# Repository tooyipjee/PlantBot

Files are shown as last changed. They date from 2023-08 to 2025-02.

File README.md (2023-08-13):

# Plant Bot: Automate Plant Care 🌱

<p align="center">
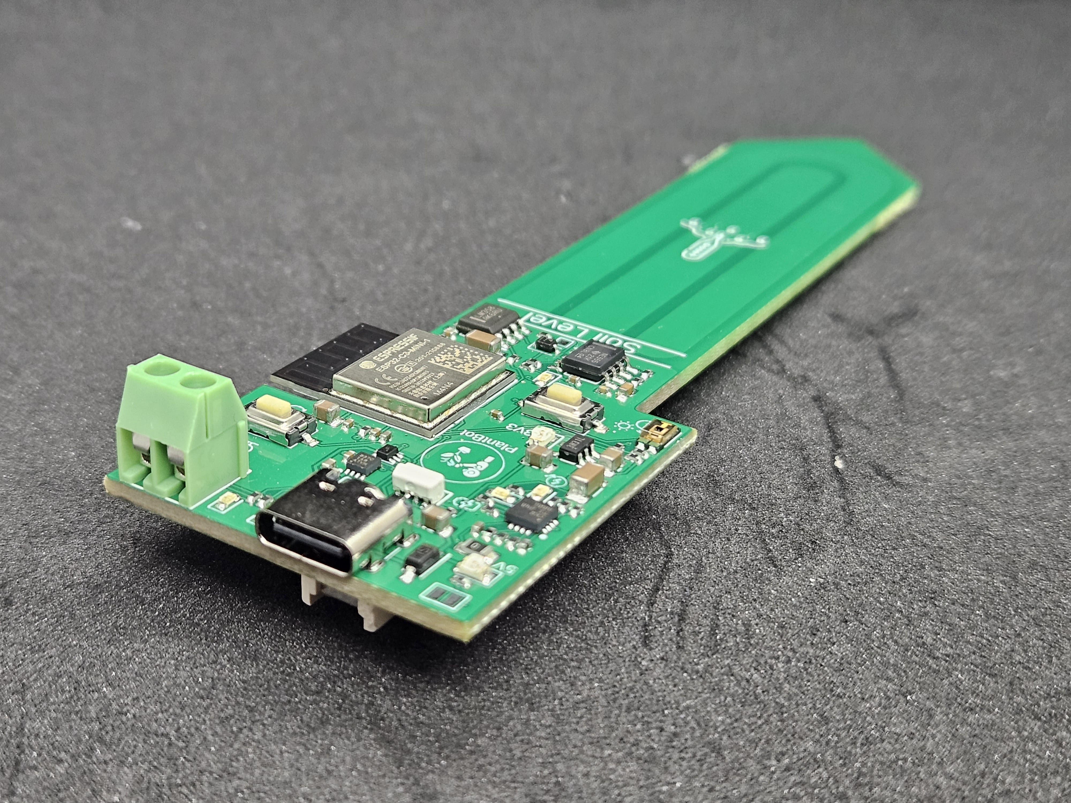
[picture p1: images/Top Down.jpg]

</p>

## High-Level Summary

Plant Bot is a cutting-edge device designed to revolutionize plant care. Powered by USB, it seamlessly integrates into your pot, transforming it into an active participant in plant care. With features like a moisture sensor, integrated pump driver, and multi-color LED control, it's the ultimate companion for every plant enthusiast.

Available on 

---

## Detailed Description

### What is it?

Plant Bot is not just a device; it's a solution to modern plant care challenges. Designed for both casual plant owners and enthusiasts, it offers:

- **Corrosion-Resistant Capacitive Moisture Sensor:** Say goodbye to guesswork. Know exactly when your plant needs water.
- **Integrated Pump Driver & LED Control:** Automated care with visual feedback. The LED's color spectrum ranges from red (indicating dry soil) to blue (indicating moist soil).
- **Connectivity:** With both WiFi and Bluetooth capabilities, stay connected with your plants from anywhere.
- **Battery-Powered Operation:** Designed as a low-power IoT device, ensuring longevity and reliability.

Leveraging open-source projects, Plant Bot supports programming via Micropython and Arduino. For advanced users, the ESP-IDF tool offers maximum customization.

---

## Use Cases

### Fully Automated Plant Care

The sample code provided showcases Plant Bot's capabilities in measuring soil moisture and light levels, taking actions based on the data. The intuitive LED color spectrum offers a visual representation of soil conditions, while an additional LED signals pump activation for hydration. Built on the ESP32 platform, it boasts comprehensive connectivity, transmitting data to platforms like Thingspeak.
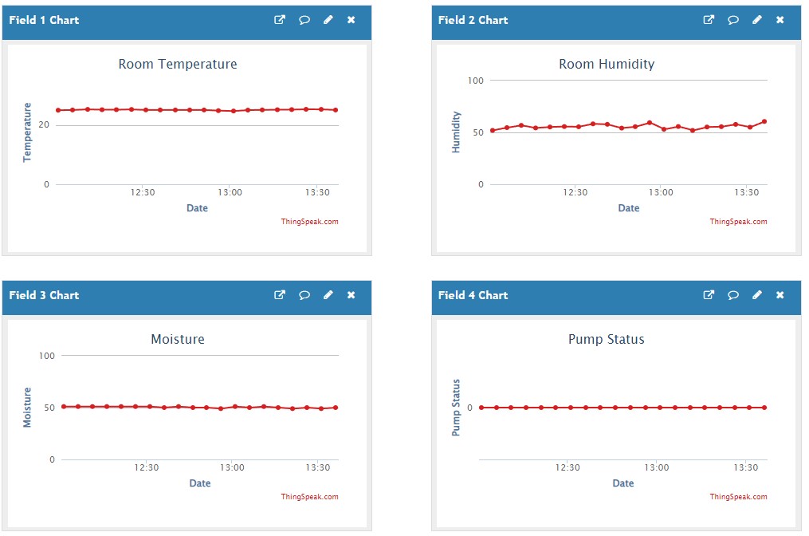
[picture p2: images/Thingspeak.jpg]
A snapshot of the data on Thingspeak showing moisture and light levels.


### Connected Plant Node

Harness the power of Plant Bot's low-power design to connect your plants to the internet wirelessly. Demos are available that allow Plant Bot to send Telegram notifications or relay measurements to IoT platforms. With efficient power consumption, a single coin cell battery can last up to a week with daily updates.

<p align="center">
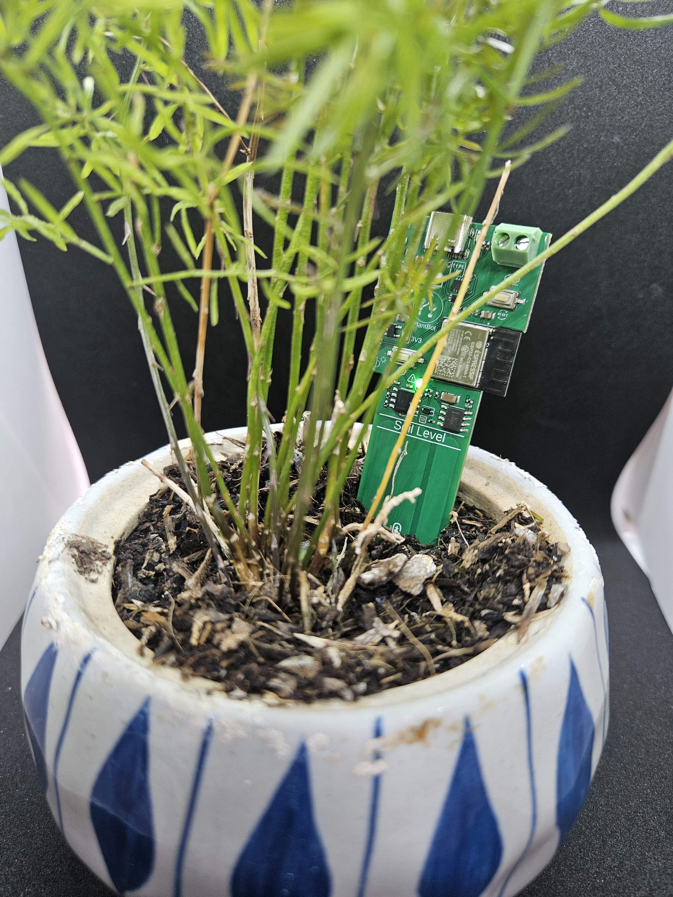
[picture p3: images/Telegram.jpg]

</p>

---

## How to Run the Demo Script

1. **Setup:** Ensure you have the Arduino IDE installed on your computer.
2. **Connect:** Plug in your ESP32-C3 device to your computer via USB.
3. **Integrated JTAG:** Ensure the JTAG is setup. In Tools, "USB CDC On Boot" is Enabled and JTAG Adapter is USB JTAG Adapter.
5. **Load Script:** Open one of the demo script provided in the Arduino IDE.
6. **Select Board:** From the 'Tools' menu, select 'Board' and choose 'ESP32-C3'.
7. **Select Port:** Select the port for the Plant-Bot device, if nothing pops up, unplug the device, hold the settings button and plug it back into the computer while still holding the button. It should appear now.
8. **Upload:** Click on the 'Upload' button to program the ESP32-C3.
9. **Monitor:** Open the Serial Monitor to view outputs and ensure the script runs successfully.

For any issues or further instructions, please refer to the documentation or raise an issue in the repo.

---

**Acknowledgments:** A special thank you to JLCPCB for their unwavering support throughout this project. Their expertise in rapid prototyping without compromising on quality has been invaluable.

## License

MIT License

Copyright (c) 2023 elektroThing

Permission is hereby granted, free of charge, to any person obtaining a copy
of this software and associated documentation files (the "Software"), to deal
in the Software without restriction, including without limitation the rights
to use, copy, modify, merge, publish, distribute, sublicense, and/or sell
copies of the Software, and to permit persons to whom the Software is
furnished to do so, subject to the following conditions:

The above copyright notice and this permission notice shall be included in all
copies or substantial portions of the Software.

THE SOFTWARE IS PROVIDED "AS IS", WITHOUT WARRANTY OF ANY KIND, EXPRESS OR
IMPLIED, INCLUDING BUT NOT LIMITED TO THE WARRANTIES OF MERCHANTABILITY,
FITNESS FOR A PARTICULAR PURPOSE AND NONINFRINGEMENT. IN NO EVENT SHALL THE
AUTHORS OR COPYRIGHT HOLDERS BE LIABLE FOR ANY CLAIM, DAMAGES OR OTHER
LIABILITY, WHETHER IN AN ACTION OF CONTRACT, TORT OR OTHERWISE, ARISING FROM,
OUT OF OR IN CONNECTION WITH THE SOFTWARE OR THE USE OR OTHER DEALINGS IN THE
SOFTWARE.

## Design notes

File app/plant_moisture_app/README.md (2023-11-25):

# plant_moisture_app

A new Flutter project.

## Getting Started

This project is a starting point for a Flutter application.

A few resources to get you started if this is your first Flutter project:

- [Lab: Write your first Flutter app](https://docs.flutter.dev/get-started/codelab)
- [Cookbook: Useful Flutter samples](https://docs.flutter.dev/cookbook)

For help getting started with Flutter development, view the
[online documentation](https://docs.flutter.dev/), which offers tutorials,
samples, guidance on mobile development, and a full API reference.

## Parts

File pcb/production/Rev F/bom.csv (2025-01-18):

Designator | Footprint | Quantity | Value | LCSC Part #
C10, C11, C12, C19, C3, C5, C8 | 0402 | 7 | 100n | C307331
C13, C15, C16, C7 | 0805 | 4 | 10u | C15850
C14 | 0402 | 1 | 1n | C1523
C17, C20, C9 | 0402 | 3 | 1u | C52923
C18, C6 | 1206 | 2 | 4.7u | C29823
C2 | 0603 | 1 | 470p | C1620
C4 | 0402 | 1 | 10n | C15195
D1 | D_SOD-323F | 1 | 1N4148WS | C2128
D10, D11, D2, D8 | 0603 | 4 | Green_0603 | C72043
D9 | B5819WSL | 1 | B5819W.SL | C8598
IC1 | SOIC127P600X175-8N | 1 | NE555DR | C7593
IC2 | SOIC127P600X175-8N | 1 | LM358DR2G | C7950
IC3 | ESP32C6MINI1N4 | 1 | ESP32-C6-MINI-1-N4 | C5736265
IC4 | AHT20 | 1 | AHT20 | C2757850
IC5 | QFN50P250X250X100-12N-D | 1 | TPS63051RMWR | C139412
IC6 | QFN50P300X300X100-17N-D | 1 | BQ24073RGTR | C15220
J1 | GT-USB-7010A | 1 | GT-USB-7010 | C963370
J2 | SM04BSRSSTBLFSN | 1 | SM04B-SRSS-TB__LF__SN_ | C160404
J3 | 2060452998404 | 1 | 2060-452_998-404 | C2765055
L1 | 0805 | 1 | 1.5uH | C2042639
Q1 | SOT95P237X125-3N | 1 | DTC143ECA-TP
Q2 | TEMT6000X01 | 1 | TEMT6000X01 | C94098
Q3 | DMP3007SFG7 | 1 | DMP3017SFG-7 | DMP3017SFG
R1, R2 | 0402 | 2 | 5.1k | C2906948
R10 | 0402 | 1 | 220 | C25091
R11, R14, R17, R18, R35, R5, R8 | 0402 | 7 | 10k | C25744
R12, R13 | 0402 | 2 | 1k | C11702
R16, R6 | 0402 | 2 | 1M | C26083
R22, R32, R33, R34, R36 | 0402 | 5 | 51k | C25794
R28, R29, R3 | 0402 | 3 | 1.5k | C25867
R30, R31, R7 | 0402 | 3 | 2.2k | C25879
R37 | 0603 | 1 | 560k | C23203
R38 | 0402 | 1 | 220k | C25767
R4 | 0402 | 1 | 2.4k | C25882
R9 | 0402 | 1 | 100 | C25076
S1, S2 | TS1101CW | 2 | TS-1101-C-W | C318938
TH2 | 0402 | 1 | 10k_NTC | C333993
TP1, TP2, TP3 | TestPoint_Pad_1.0x1.0mm | 3 | TestPoint_Alt
U2 | CR2032BS61 | 1 | CR2032-BS-6-1 | C70377

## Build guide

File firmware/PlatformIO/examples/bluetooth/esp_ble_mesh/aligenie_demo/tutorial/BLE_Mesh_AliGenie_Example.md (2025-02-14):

| Supported Targets | ESP32 |
| --- | ----- |

ESP BLE Mesh AliGenie Example
=============================

This demo shows how to use AliGenie to control the LED state. The basic procedures are as follows:

1. Go to the Ali IoT platform to apply for device triples.
2. Configure triples.
3. Download and run this demo.
4. Use AliGenie speakers or AliGenie app for BLE Mesh to provision.
5. After devices are provisioned, use voice interaction or app to control the LED state with AliGenie speakers.

# Basic Procedures

## 1. Apply Triples

## 1.1 Create Project

The first step in using the Ali IoT platform is to create a project. Data between projects is isolated from each other. Steps:

1. Log in to the console of the [Ali IoT platform](https://living.aliyun.com/?spm=a2c4g.11186623.2.13.4d219931TRSWJO).
2. Click Create Project.
3. Configure the project name.

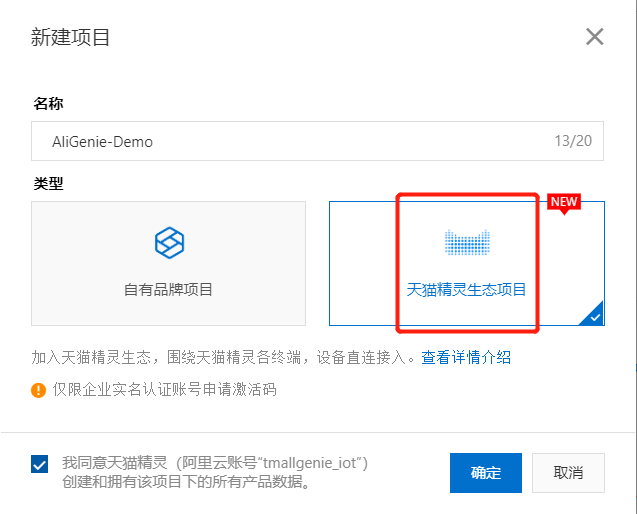
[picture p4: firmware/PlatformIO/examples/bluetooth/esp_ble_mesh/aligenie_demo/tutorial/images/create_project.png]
Create Project


## 1.2 Create Product

In each project, you can create multiple products. After the product is created, you can abstract the actual product into a data model composed of attributes, services, and events by defining product functions to facilitate cloud management and data interaction.

1. On the main project page, click Create New Product.
2. Configure product parameters
3. Click Finish. After the product is successfully created, it will automatically enter the product function definition page.

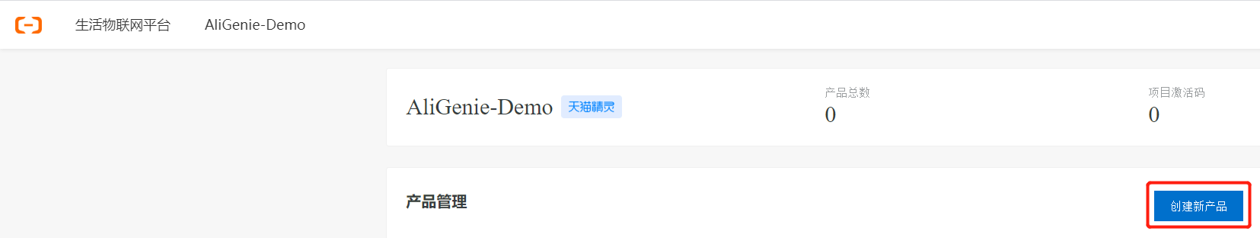
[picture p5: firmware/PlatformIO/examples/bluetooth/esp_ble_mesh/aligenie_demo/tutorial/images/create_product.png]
Create Product


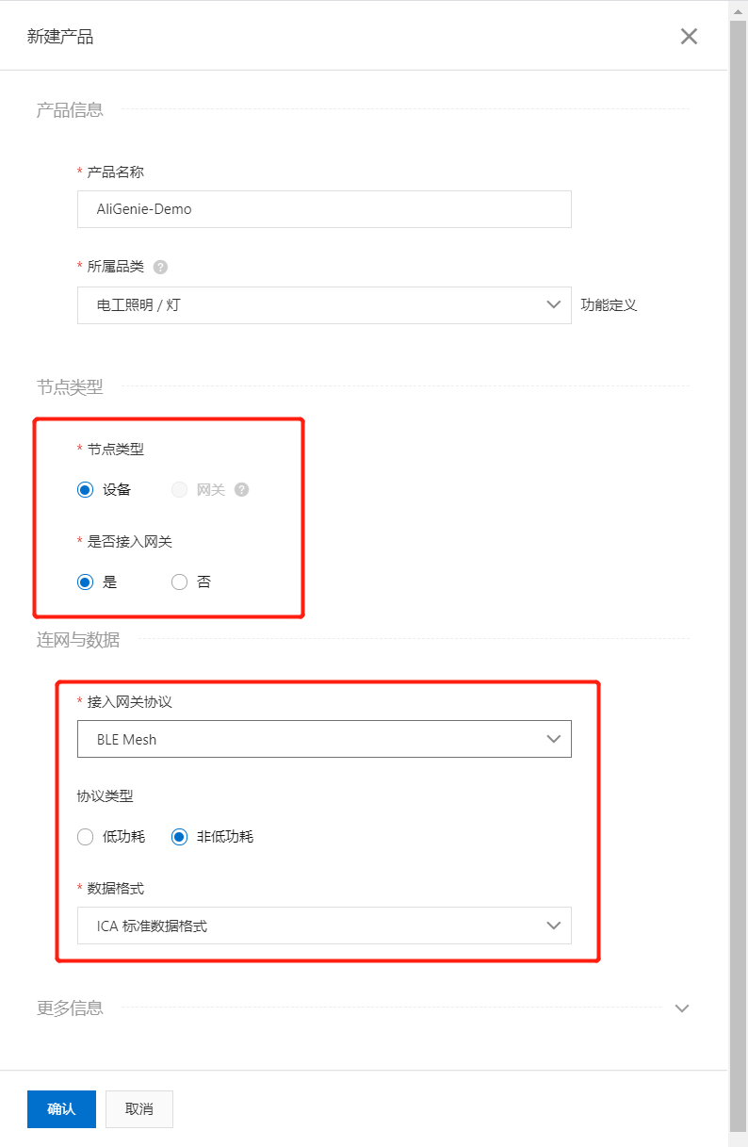
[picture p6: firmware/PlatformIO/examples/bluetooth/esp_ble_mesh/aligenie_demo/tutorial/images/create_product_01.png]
Create Product


## 1.3 Definition Features

The platform provides default standard functions for each category. After the product is created, the function definition page automatically displays the default standard functions of the product.

You can add or modify features according to the following steps. On the product function definition page, click Add function corresponding to the standard function.

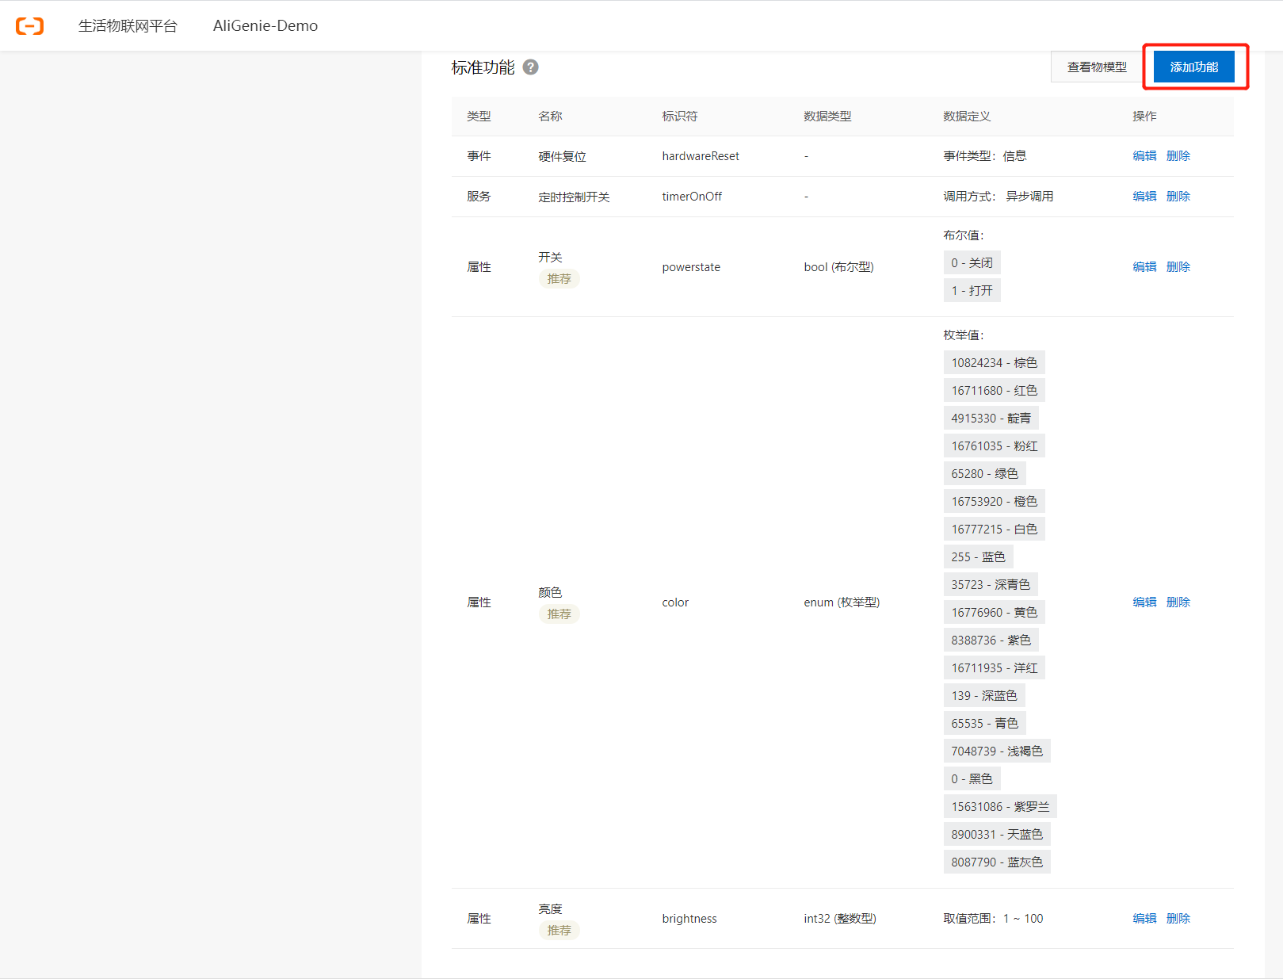
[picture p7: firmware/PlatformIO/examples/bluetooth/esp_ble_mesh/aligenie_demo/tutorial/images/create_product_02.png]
Create Product


## 1.4 Configure App

The life IoT platform provides App services, which simplifies App development tasks. You can realize the data communication between the App and the platform through simple configuration, and achieve the effect of human-computer interaction.

1. Click Next: Human-Computer Interaction to enter the product-human-computer interaction page.
2. Turn on the switch to control the product using the public version App.
3. Click the selection panel. Select a device panel in the Theme Panel tab in the Select Product Panel dialog box or design a panel by yourself in the custom panel.
4. Install the public version App "Cloud Intelligence". Click Install now, select the development version, and then scan the code to download the development version of the public version of the App.
5. Configure the boot page for device network configuration.

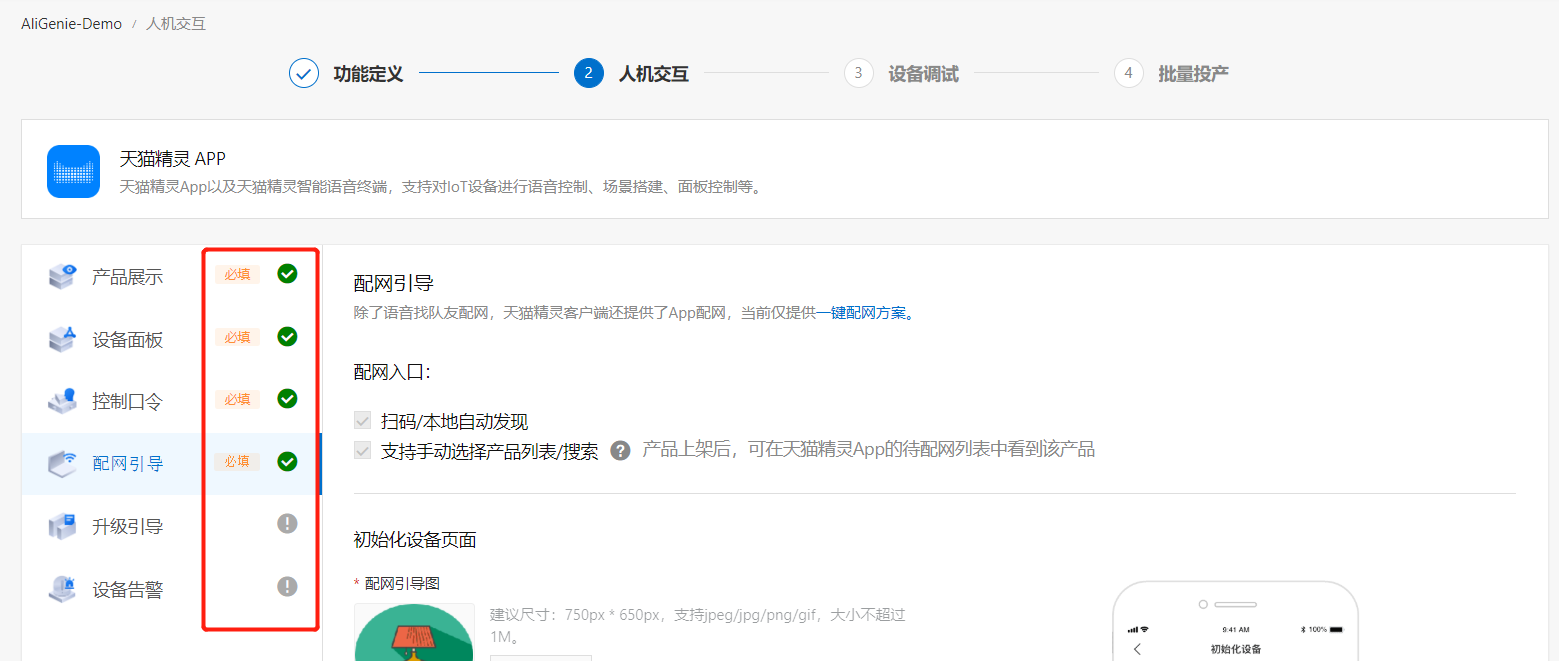
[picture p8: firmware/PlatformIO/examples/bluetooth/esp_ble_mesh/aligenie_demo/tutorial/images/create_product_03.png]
Create Product


## 1.2 Add Debug Device

The device must use the unique device certificate (ProductID, DeviceName, DeviceSecret) issued by the platform to access the Ali IoT platform.

1. Click Next: Device debugging, enter the product-device debugging page.
2. Select the corresponding module in the selection of authentication module/chip, and it is recommended to use the module that has been certified by Ali.
3. Click Add Test Device in Test Device.
4. Configure the device name. DeviceName can also be left unconfigured, and the system automatically generates the device name.
5. Click OK, the interface displays the device certificate of the test device. The activation credentials (ProductID, DeviceName, DeviceSecret) that need to be burned into the device are shown in the red box in the figure below.

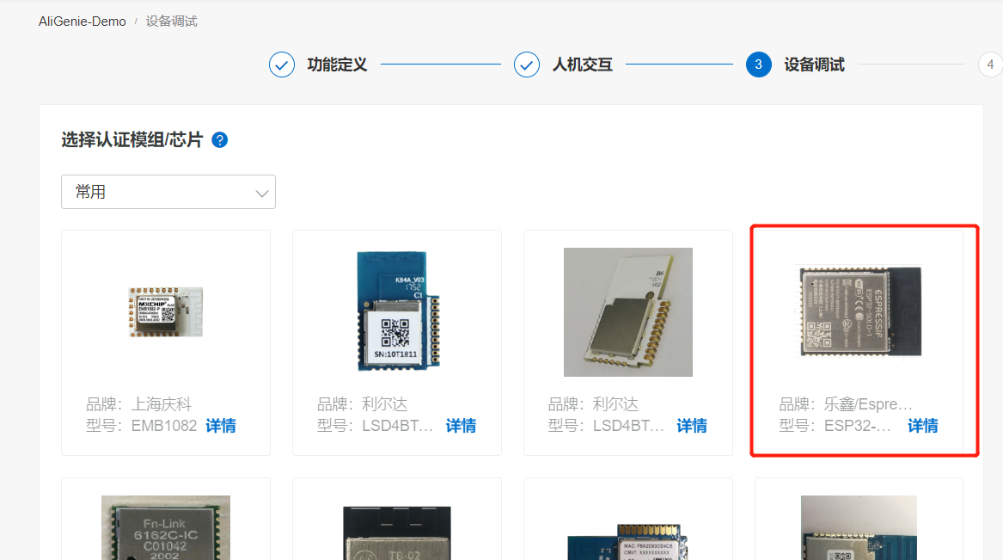
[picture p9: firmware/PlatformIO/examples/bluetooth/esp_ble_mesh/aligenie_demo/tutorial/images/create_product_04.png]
Create Product


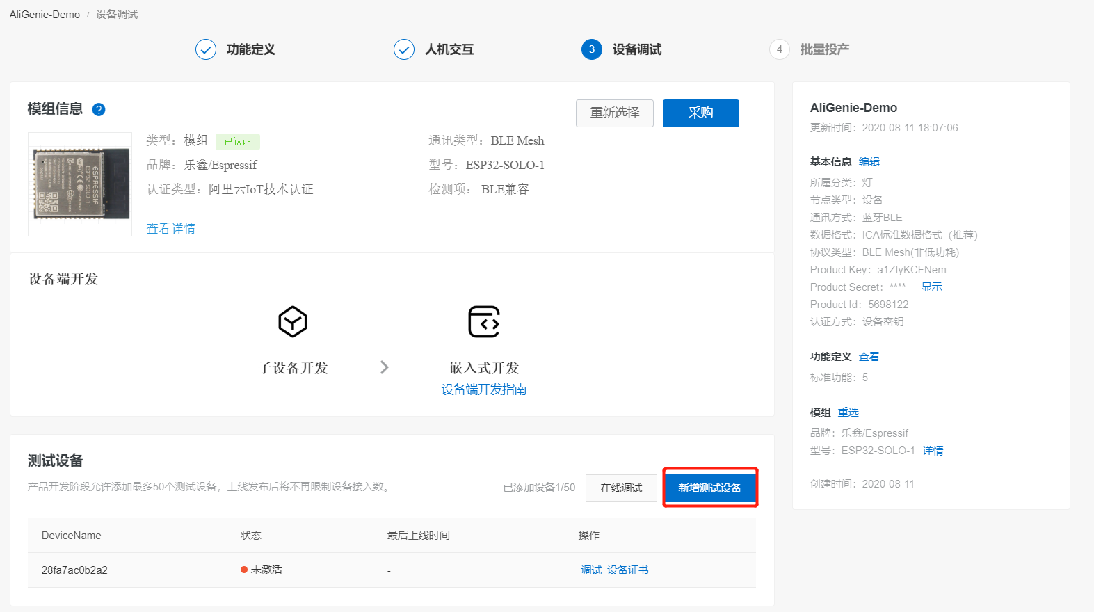
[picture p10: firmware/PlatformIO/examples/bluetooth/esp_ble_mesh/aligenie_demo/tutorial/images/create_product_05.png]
Create Product


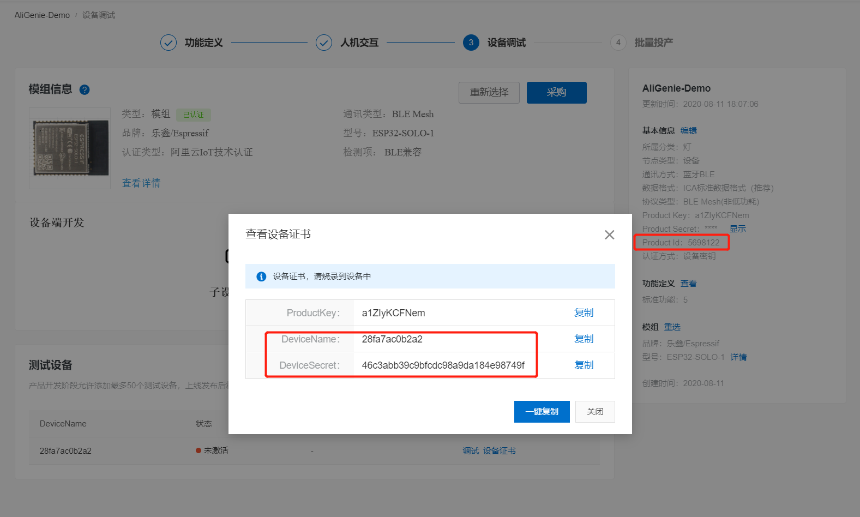
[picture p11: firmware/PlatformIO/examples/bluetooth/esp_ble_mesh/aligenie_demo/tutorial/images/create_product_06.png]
Create Product


## 2. Configure triples

1. Enter the examples/bluetooth/esp_ble_mesh/aligenie_demo directory and run `idf.py menuconfig`
2. Configure device triples information, save and exit after modification.

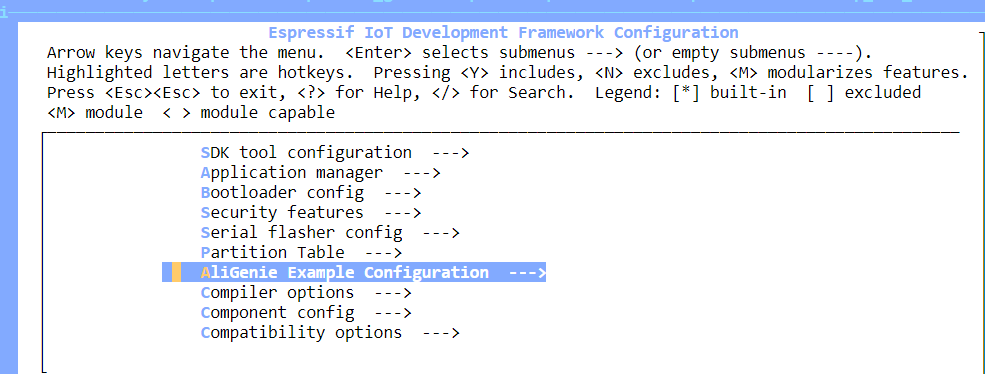
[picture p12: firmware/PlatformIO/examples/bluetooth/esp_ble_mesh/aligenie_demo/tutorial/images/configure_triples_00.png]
Configure triples


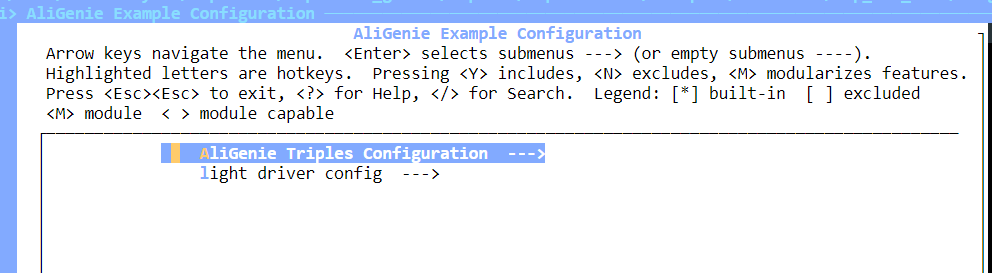
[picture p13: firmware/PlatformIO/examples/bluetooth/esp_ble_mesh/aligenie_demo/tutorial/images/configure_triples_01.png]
Configure triples


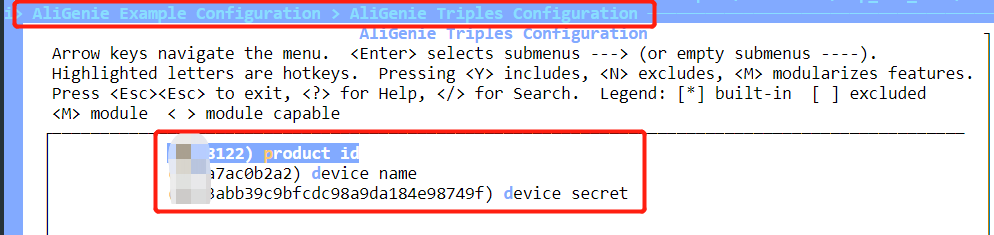
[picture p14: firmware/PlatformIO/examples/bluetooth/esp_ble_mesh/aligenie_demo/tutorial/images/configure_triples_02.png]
Configure triples


## 3. Config LED GPIO

1. To use color-adjustable RGB lights, three GPIOs, RED, GREEN, and BLUE, need to be configured.

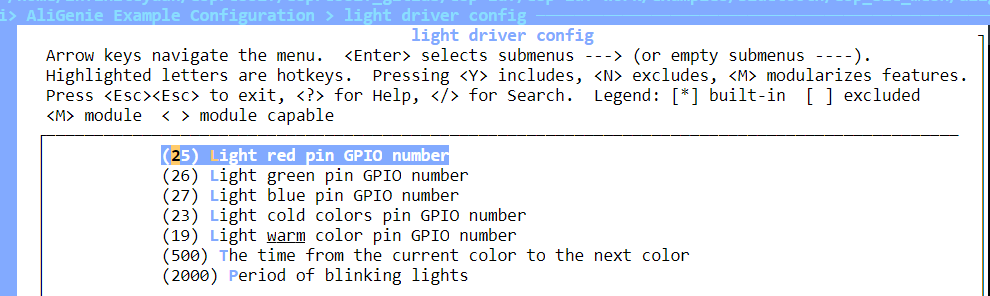
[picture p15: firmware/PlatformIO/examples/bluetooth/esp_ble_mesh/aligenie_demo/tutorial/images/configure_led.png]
Configure LED


## 4. Download and run this demo

1. After all configurations are completed, you can run `idf.py flash monitor` to download and monitor.
2. After the download is complete, you can see this log.

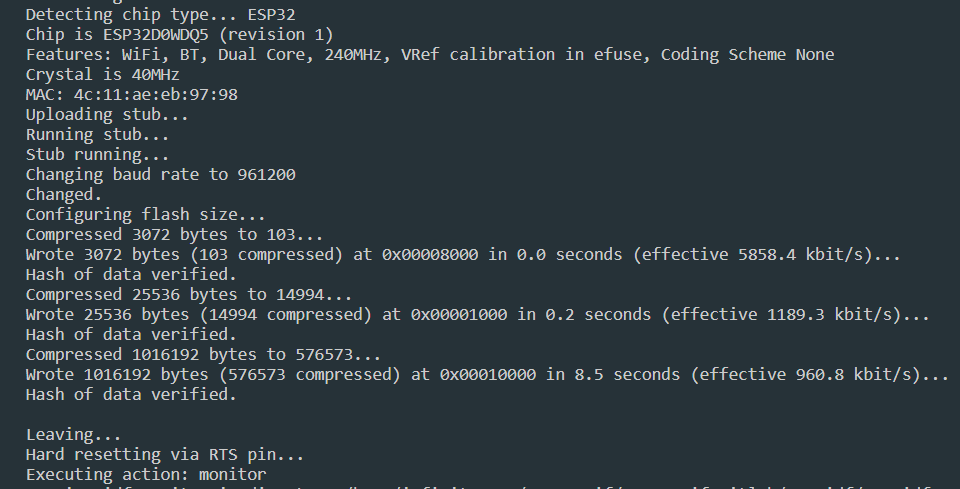
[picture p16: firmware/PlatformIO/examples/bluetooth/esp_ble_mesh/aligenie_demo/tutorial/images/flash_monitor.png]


## 5. Provision

1. When the device is powered on for the first time, the GREEN light will blink, indicating that the device has not been provisioned yet.
2. We can say "天猫精灵，发现智能设备" to the AliGenie speaker.
3. When the speaker finds the device and prompts whether to connect, we say "连接" to the AliGenie speaker, and you can start provisioning the device.
4. Next we can use voice to control the lights, for example:"天猫精灵，开灯"、"天猫精灵，关灯"、"天猫精灵，把灯调整成蓝色"、"天猫精灵，把灯调整成绿色"…………

## 6. Reset

1. The device can be reset by repeatedly resetting the device three times.
2. Each reset operation needs to wait until the light is on before proceeding.

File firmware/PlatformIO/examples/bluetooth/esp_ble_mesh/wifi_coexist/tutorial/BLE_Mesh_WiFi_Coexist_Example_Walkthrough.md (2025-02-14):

# Introduction

This demo demonstrates the Wi-Fi and Bluetooth (BLE/BR/EDR) coexistence feature of ESP32. Simply put, users can use the Wi-Fi function while operating Bluetooth. In this demo,

* The Wi-Fi function is demonstrated by measuring its transfer rate, using the `iperf` protocol;
* The Bluetooth function is demonstrated by the fast provisioning function. Details can be seen in `fast_prov_server`.

> Note: In this demo, you call wifi API and bluetooth API to achieve the functions you want. such as `wifi_get_local_ip` API and `esp_ble_mesh_provisioner_add_unprov_dev` API.

# What You Need

Download and flash the `wifi_coexist` project to your ESP32 development board and then use the following commands to get started with this demo.

1. Connect your development board to the Wi-Fi network by entering the `sta ssid password` command in your serial port tool.
	- For example, you should enter `sta test_wifi 12345678` if you want to connect your board to a network with a SSID of `test_wifi` and a password of `12345678`.

2. Start a TCP server by entering the `iperf -s -i 3 -t 1000` command in your serial port tool, which prints the current transfer rate of the Wi-Fi network the board connects to.

3. Start a TCP client by entering the `iperf -c board_IP_address -i 3 -t 60` command in your PC terminal.
	- For example, you should enter `iperf -c 192.168.10.42 -i 3 -t 60`, if the IP address of your board is 192.168.10.42.

Meanwhile, you can use the Bluetooth function during the whole process, for example, controlling the LED indicator on your board.

> Note:
>
> 1. Please use the correct serial port number for connecting your board when entering commands in your serial port tool;
> 2. Your PC and board should connect to the same Wi-Fi network;

# Project Directory

The `wifi_coexist` demo contains the following files and subfolders:

```
$ tree examples/bluetooth/esp_ble_mesh/wifi_coexist
├── main        /* Stores the `.c` and `.h` application code files for this demo */
├── components  /* Stores the `.c` and `.h` iperf code files for this demo */
├── Makefile    /* Compiling parameters for the demo */
├── README.md   /* Quick start guide */
├── build
├── sdkconfig      /* Current parameters of `idf.py menuconfig` */
├── sdkconfig.defaults   /* Default parameters of `idf.py menuconfig` */
├── sdkconfig.old      /* Previously saved parameters of `idf.py menuconfig` */
└── tutorial         /* More in-depth information about the demo */
```

The `main` folder mainly implements the BLE Mesh feature.  Details can be seen in `fast_prov_server`.

The `components` folder mainly implements the Wi-Fi feature, which allows some basic commands and `iperf-related` test commands.

> Note:
>
> [Iperf](https://iperf.fr) is a tool for active measurements of the maximum achievable bandwidth on IP networks. It supports tuning of various parameters related to timing, buffers and protocols (TCP, UDP, SCTP with IPv4 and IPv6).

# Example Walkthrough

## Main Entry Point

The program’s entry point is the `app_main()` function.

## Initialization

The code block below first initialize the board, then its bluetooth-related functions (including the Bluetooth and BLE Mesh) and the Wi-Fi console.

```c
void app_main(void)
{
    esp_err_t err;

    ESP_LOGI(TAG, "Initializing...");

    err = board_init();
    if (err) {
        ESP_LOGE(TAG, "board_init failed (err %d)", err);
        return;
    }

    err = bluetooth_init();
    if (err) {
        ESP_LOGE(TAG, "esp32_bluetooth_init failed (err %d)", err);
        return;
    }

    /* Initialize the Bluetooth Mesh Subsystem */
    err = ble_mesh_init();
    if (err) {
        ESP_LOGE(TAG, "Bluetooth mesh init failed (err %d)", err);
        return;
    }

    wifi_console_init();
}
```

### Initializing the Board

This demo calls the `board_init` function to:

1. First initialize three pins for the LED indicator, and set its initial status to OFF (i.e. initialize the `led_state[i].previous` variable to `LED_OFF`).

```c
for (int i = 0; i < 3; i++) {
    esp_rom_gpio_pad_select_gpio(led_state[i].pin);
    gpio_set_direction(led_state[i].pin, GPIO_MODE_OUTPUT);
    gpio_set_level(led_state[i].pin, LED_OFF);
    led_state[i].previous = LED_OFF;
}
```

2. Create a task named `led_action_thread` for controlling the status of the light, and then a queue named `led_action_queue` for storing status data, whose format is defined in `struct _led_state`.

```c
led_action_queue = xQueueCreate(60, sizeof(struct _led_state));
ret = xTaskCreate(led_action_thread, "led_action_thread", 4096, NULL, 5, NULL);
```

3. The `led_action_thread` task continuously sets the status of the LED indicator by calling the `gpio_set_level` function, using status data obtains data from the `led_action_queue` queue.

```c
static void led_action_thread(void *arg)
{
    struct _led_state led = {0};

    while (1) {
        if (xQueueReceive(led_action_queue, &led, (TickType_t)portMAX_DELAY)) {
            ESP_LOGI(TAG, "%s: pin 0x%04x onoff 0x%02x", __func__, led.pin, led.current);
            /* If the node is controlled by phone, add a delay when turn on/off led */
            if (fast_prov_server.primary_role == true) {
                vTaskDelay(50 / portTICK_PERIOD_MS);
            }
            gpio_set_level(led.pin, led.current);
        }
    }
}
```

### Initializing the Bluetooth

This demo calls the `bluetooth_init` function to:

1. First initialize the non-volatile storage library, which allows saving key-value pairs in flash memory and is used by some components. You can save the node's keys and configuration information at `menuconfig` --> `Bluetooth Mesh support` --> `Store Bluetooth Mesh key and configuration persistently`:

	 ```c
    esp_err_t ret = nvs_flash_init();
    if (ret == ESP_ERR_NVS_NO_FREE_PAGES || ret == ESP_ERR_NVS_NEW_VERSION_FOUND) {
        ESP_ERROR_CHECK(nvs_flash_erase());
        ret = nvs_flash_init();
    }
    ESP_ERROR_CHECK( ret );
	 ```

2. Initializes the BT controller by first creating a BT controller configuration structure named `esp_bt_controller_config_t` with default settings generated by the `BT_CONTROLLER_INIT_CONFIG_DEFAULT()` macro. The BT controller implements the Host Controller Interface (HCI) on the controller side, the Link Layer (LL) and the Physical Layer (PHY). The BT Controller is invisible to the user applications and deals with the lower layers of the BLE stack. The controller configuration includes setting the BT controller stack size, priority and HCI baud rate. With the settings created, the BT controller is initialized and enabled with the `esp_bt_controller_init()` function:

	```c
	esp_bt_controller_config_t bt_cfg = BT_CONTROLLER_INIT_CONFIG_DEFAULT();
	ret = esp_bt_controller_init(&bt_cfg);
	```

	Next, the controller is enabled in BLE Mode.

	```c
	ret = esp_bt_controller_enable(ESP_BT_MODE_BLE);
	```
	The controller should be enabled in `ESP_BT_MODE_BTDM`, if you want to use the dual mode (BLE + BT). There are four Bluetooth modes supported:

	* `ESP_BT_MODE_IDLE`: Bluetooth not running
	* `ESP_BT_MODE_BLE`: BLE mode
	* `ESP_BT_MODE_CLASSIC_BT`: BT Classic mode
	* `ESP_BT_MODE_BTDM`: Dual mode (BLE + BT Classic)

	After the initialization of the BT controller, the Bluedroid stack, which includes the common definitions and APIs for both BT Classic and BLE, is initialized and enabled by using:

	```
	ret = esp_bluedroid_init();
	ret = esp_bluedroid_enable();
	```

### Initializing the BLE Mesh

This demo calls the `ble_mesh_init` function to:

1. Initialize the board's uuid by setting the `dev_uuid` variable, which is used to distinguish devices when provisioning.

```c
static esp_err_t ble_mesh_init(void)
{
    esp_err_t err;

    /* First two bytes of device uuid is compared with match value by Provisioner */
    memcpy(dev_uuid + 2, esp_bt_dev_get_address(), 6);

    esp_ble_mesh_register_prov_callback(example_ble_mesh_provisioning_cb);
    esp_ble_mesh_register_custom_model_callback(example_ble_mesh_custom_model_cb);
    esp_ble_mesh_register_config_client_callback(example_ble_mesh_config_client_cb);
    esp_ble_mesh_register_config_server_callback(example_ble_mesh_config_server_cb);

    err = esp_ble_mesh_init(&prov, &comp);
    if (err != ESP_OK) {
        ESP_LOGE(TAG, "%s: Failed to initialize BLE Mesh", __func__);
        return err;
    }
    ...
    return ESP_OK;
}
```
2. Register the provisioning callback function in the BLE Mesh stack with `esp_ble_mesh_register_prov_callback(esp_ble_mesh_prov_cb)`, among which `esp_ble_mesh_prov_cb` is used to handle events thrown by protocol stations. This requires the user to implement it himself, and also needs to know the meaning of the event and how to trigger it. For example: The `ESP_BLE_MESH_PROVISIONER_PROV_LINK_OPEN_EVT` event is triggered when the provisioner starts provisioning unprovisioned device, and is handled in the `example_ble_mesh_provisioning_cb` function. Note that you need to register this function with the BLE Mesh protocol stack by calling the `esp_ble_mesh_register_prov_callback` API.

	```c
	ESP_BLE_MESH_PROVISIONER_PROV_LINK_OPEN_EVT,                /*!< Provisioner establish a BLE Mesh link event */

	static void example_ble_mesh_provisioning_cb(esp_ble_mesh_prov_cb_event_t event,
        esp_ble_mesh_prov_cb_param_t *param)
	{
   	     esp_err_t err;

         switch (event) {
    	  case ESP_BLE_MESH_PROVISIONER_PROV_LINK_OPEN_EVT:
        	ESP_LOGI(TAG, "ESP_BLE_MESH_PROVISIONER_PROV_LINK_OPEN_EVT");
       	 provisioner_prov_link_open(param->provisioner_prov_link_open.bearer);
        	break;
   	 }
	}

	esp_ble_mesh_register_prov_callback(example_ble_mesh_provisioning_cb);
	```
3. Register BLE Mesh callback for user-defined Models' operations with `esp_ble_mesh_register_custom_model_callback(esp_ble_mesh_model_cb)`.

4. Register BLE Mesh Config Client Model callback with `esp_ble_mesh_register_config_client_callback(example_ble_mesh_config_client_cb)`.
5. Register BLE Mesh Config Server Model callback with `esp_ble_mesh_register_config_server_callback(example_ble_mesh_config_server_cb)`.

6. Initialize the BLE Mesh module by calling the `esp_ble_mesh_init(&prov, &comp)` API, which initializes the provisioning capabilities and composition data information. Registered information is stored in the `prov` struct, which is essentially a composition of one or more Models.

### Initializing the Wi-Fi Console

This demo calls the `wifi_console_init` function:

```c
    initialise_wifi();

    esp_console_repl_t *repl = NULL;
    esp_console_repl_config_t repl_config = ESP_CONSOLE_REPL_CONFIG_DEFAULT();
    esp_console_dev_uart_config_t uart_config = ESP_CONSOLE_DEV_UART_CONFIG_DEFAULT();
    // init console REPL environment
    ESP_ERROR_CHECK(esp_console_new_repl_uart(&uart_config, &repl_config, &repl));

    register_wifi();

    // start console REPL
    ESP_ERROR_CHECK(esp_console_start_repl(repl));
```

1. Initialize the basic Wi-Fi function by calling `initialise_wifi`, which sets

	* the Current Wi-Fi power save type to `WIFI_PS_MIN_MODEM`, which indicates the station wakes up to receive beacon every DTIM period
	* the Wi-Fi API configuration storage type to `WIFI_STORAGE_RAM`, which indicates all configuration will only be stored in the embedded memory
	* the Wi-Fi operating mode to `WIFI_MODE_STA`, which allows the board to work in Station mode.

2. Create a UART based console REPL by calling the `esp_console_new_repl_uart` function.
3. Register the commands by calling the `register_wifi` function.
	* An example of registering a `restart` command with a `restart()` function to handle this command can be seen below. After the initialization, you can enter the `restart` command in your serial port tool to call the `restart()` function.
        ```c
            static int restart(int argc, char **argv)
            {
                ESP_LOGI(TAG, "Restarting");
                esp_restart();
            }
            const esp_console_cmd_t restart_cmd = {
                .command = "restart",
                .help = "Restart the program",
                .hint = NULL,
                .func = &restart,
            };
        ```

    Note that the `sta`,`scan`,`ap`,`query`,`iperf`,`restart` and `heap` commands are supported in this demo.

4. Start the REPL by calling `esp_console_start_repl`. The repl task internally will read data from the command line and then invoke the handler previously registered.

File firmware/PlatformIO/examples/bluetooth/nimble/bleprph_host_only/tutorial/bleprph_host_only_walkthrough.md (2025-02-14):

# BLE Peripheral Example Walkthrough

## Introduction

The tutorial is focused on how to implement the custom transport in the application and register it with nimble-host. This example has the exact same working as bleprph except the transport used is custom UART transport written in `"main/uart_driver.c"` file. The controller is disabled for this example, the nimble-host tries to communicate with the external connected controller using UART transport.

Note: This walkthrough only covers the transport used by the application, for detailed explanation see the [bleprph_walkthrough](../../bleprph/tutorial/bleprph_walkthrough.md)
## Hardware Setup

This example uses esp32 chip to run the example `bleprph_host_only` that runs the nimble-host and sends and receives the commands and events using uart. The another chip used is esp32c6 that runs the controller `esp-idf/examples/bluetooth/nimble/hci` example that runs the controller and receives commands and sends events using UART. Below is the setup of esp32 and esp32c6.

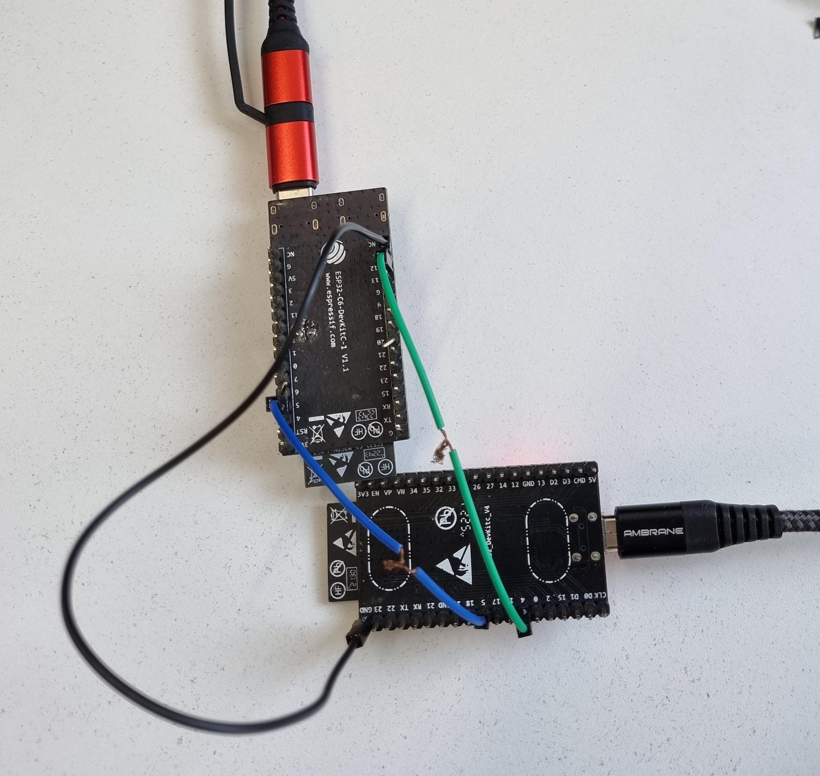
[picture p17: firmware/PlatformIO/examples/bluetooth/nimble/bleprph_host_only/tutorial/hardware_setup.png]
Hardware Setup


Note that the esp32 gpio pins tx=4 and rx=5 are configurable using idf.py menuconfig -> example config -> Uart Configuration. The tx pin of one chip connects to the rx pin of the other and vice versa.

The gpio pins for hci example are configurable through idf.py menuconfig -> Component config -> Bluetooth -> Controller Options -> HCI Config

Below is the pin connection chart for Esp32(Running host) and esp32c6(Running controller).

| Esp32 (Signal) | Esp32 (GPIO Pin)  | C6 (Signal) | C6 (GPIO Pin) |
|---|---|---|---|
| Rx | 5 | Tx | 5 |
| Tx | 4 | Rx | 12 |

The same pin configuration could be used for esp32c3, esp32s3, esp32c2 and esp32c6.
For esp32p4 use the following configuration.

| P4 (Signal) | P4 (GPIO Pin) | C6 (Signal) | C6 (GPIO Pin) |
|---|---|---|---|
| Rx | 22 | Tx | 5 |
| Tx | 21 | Rx | 12 |

```c
#define UART_TX_PIN              (4)
#define UART_RX_PIN              (5)
#define UART_RTS_PIN             (19)
#define UART_CTS_PIN             (23)
```

## Main Entry Point

The program’s entry point is the app_main() function:

```c
void
app_main(void)
{
    int rc;

    /* Initialize NVS — it is used to store PHY calibration data */
    esp_err_t ret = nvs_flash_init();
    if (ret == ESP_ERR_NVS_NO_FREE_PAGES || ret == ESP_ERR_NVS_NEW_VERSION_FOUND) {
        ESP_ERROR_CHECK(nvs_flash_erase());
        ret = nvs_flash_init();
    }
    ESP_ERROR_CHECK(ret);

    hci_uart_open();
    ret = nimble_port_init();
    if (ret != ESP_OK) {
        ESP_LOGE(tag, "Failed to init nimble %d ", ret);
        return;
    }
    ....
    ....
}
```
In the main function `hci_uart_open()` configures the uart with necessary parameters like baud_rate, parity, etc. The file [uart_driver.c](../main/uart_driver.c) has all the uart transport code along with the necessary apis mandated by nimble-host. `ble_transport_to_ll_acl_impl` is the api used to send the data to the controller. and `ble_transport_to_ll_cmd_impl` is used to send the command to the controller. These two apis are implemented as they are necessary. Along with these two apis, any data that is received in the rx direction is redirected to the host using `ble_transport_to_hs_evt` and `ble_transport_to_hs_acl` apis.

## Conclusion
1. This example covered how to write the custom transport layer and use it with nimble-host.
2. The example used the esp-hosted network-adapter example flashed on esp32c6 connected through UART to test this demo.
3. In the similar fashion the external controller could be connected.

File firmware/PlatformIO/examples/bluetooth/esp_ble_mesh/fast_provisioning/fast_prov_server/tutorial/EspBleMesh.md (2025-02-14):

# Demo Function

This demo demonstrates the fast provisioning of ESP BLE Mesh network and how to use the EspBleMesh app to control an individual provisioned node or all the provisioned nodes.
 
A video of this example can be seen from [here](https://dl.espressif.com/BLE/public/ESP32_BLE_Mesh_Fast_Provision.mp4).

# What You Need 

* [EspBleMesh App for Android](https://github.com/EspressifApp/EspBLEMeshForAndroid/releases/tag/v1.1.0)
* [esp-idf](https://github.com/espressif/esp-idf)
* ESP32 Development Boards

> Note:
> 
> 1. Please flash the [`fast_prov_server`](../../) to the development boards first;
> 2. To have a better understanding of the performance of the BLE Mesh network, we recommend that at least 3 devices should be added in your network.
> 3. We recommend that you solder LED indicators if your development board does not come with lights. 
> 4. Please check the type of board and LED pin definition enabled in `Example BLE Mesh Config` by running `idf.py menuconfig`

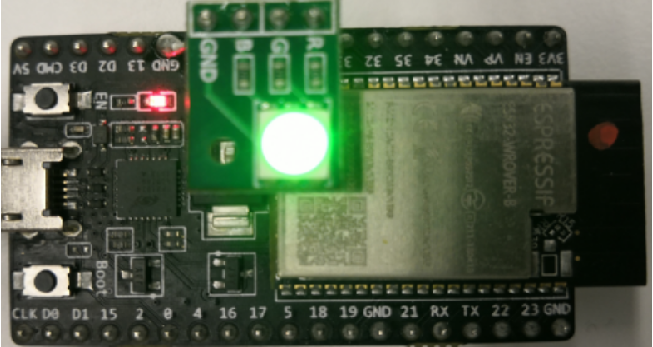
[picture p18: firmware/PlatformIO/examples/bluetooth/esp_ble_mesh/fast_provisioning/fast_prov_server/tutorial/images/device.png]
Board


# Flash and Monitor

1.	Enter the directory: 
examples/bluetooth/esp_ble_mesh/fast_provisioning/fast_prov_server
2.	Make sure that the `IDF_PATH` environment variable was set in accordance with your current IDF path
3. Check the version of your toolchain. Version 4.1 or newer should be used.
 
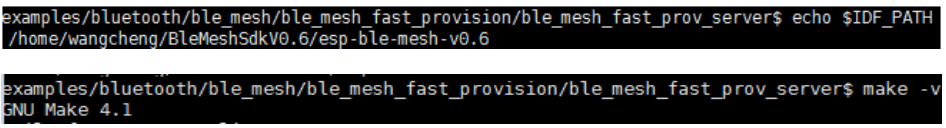
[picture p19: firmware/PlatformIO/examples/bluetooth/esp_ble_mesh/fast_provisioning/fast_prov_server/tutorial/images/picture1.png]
Checkenvironment


4. Run `idf.py -p PORT flash` to compile codes and flash the codes to the device.

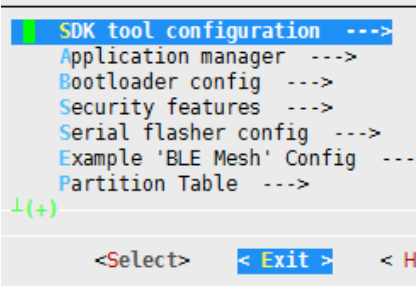
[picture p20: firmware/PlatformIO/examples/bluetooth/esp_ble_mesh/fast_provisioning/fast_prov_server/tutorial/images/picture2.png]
compiledcode


> Note: 
> 
> Please click on the Exit button if you see the following windows.

5. Please establish a connection between your device and PC, using the correct serial number, if you want to monitor the operation of this device on PC. 

# How to Use the App

Please launch the `EspBleMesh` app, and follow the steps described below to establish a BLE Mesh network and control any individual node or all the nodes.

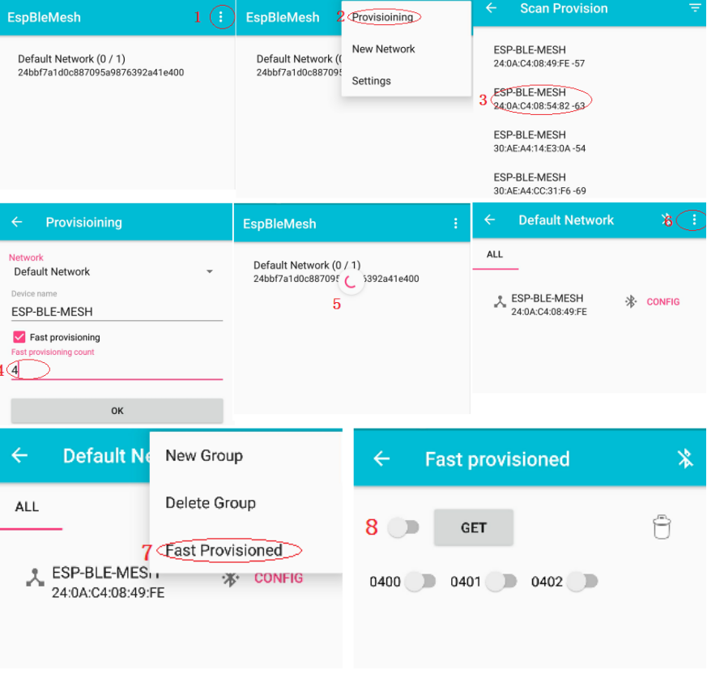
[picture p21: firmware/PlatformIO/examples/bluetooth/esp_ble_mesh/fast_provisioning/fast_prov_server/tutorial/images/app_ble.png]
App steps

1. Click on the upper left corner to see more options;
2. Click on **Provisioning** to scan nearby unprovisioned devices;
3. Choose any unprovisioned devices in the scanned list;
4. Enter the number of devices you want to add in your mesh network;
> Note: 
> 
> If you only want to use the normal provisioning feature，You don't check the option for fast provisioning.
5. Wait until all the devices are provisioned;
6. Click on the upper left corner to see more options;
7. Click on **Fast Provisioned** to see all the provisioned devices;
8. Control your devices.

> Note: 
> 
> Please disable your Bluetooth function on your phone, enable it and try again, if you have encountered any connection issues.

# Procedure

## Role

* Phone - Top Provisioner
* The device that has been provisioned by Phone - Primary Provisioner
* Devices that have been provisioned and changed to the role of a provisioner - Temporary Provisioner
* Devices that have been provisioned but not changed to the role of a provisioner - Node

## Interaction

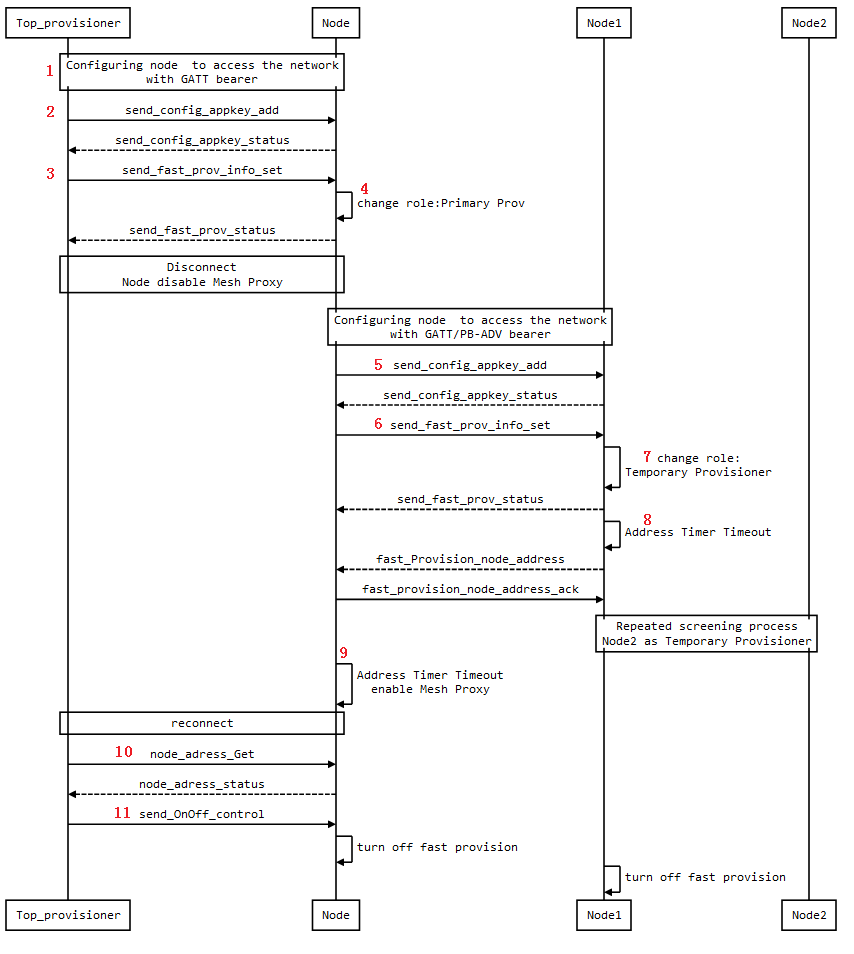
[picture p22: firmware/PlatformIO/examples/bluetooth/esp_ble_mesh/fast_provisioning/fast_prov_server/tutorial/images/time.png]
Interaction

1. The Top Provisioner configures the first device to access the network with the GATT bearer.
2. The Top Provisioner sends the `send_config_appkey_add` message to allocate the Appkey to this device. 
3. The Top Provisioner sends the `send_fast_prov_info_set` message to provide the necessary information so the device can be changed to a Primary Provisioner.
4. The device calls the `esp_ble_mesh_set_fast_prov_action` API to change itself into the role of a Primary Provisioner and disconnects with the Top Provisioner.
5. The Primary Provisioner sends the `send_config_appkey_add` message to allocate the Appkey to an other device.
6. The Primary Provisioner sends the `send_fast_prov_info_set` message to provide the necessary information so the device can be changed to a Temporary Provisioner.
7. The device calls the `esp_ble_mesh_set_fast_prov_action` API to change itself into the role of a Temporary Provisioner and starts its address timer.
8. The Temporary Provisioner collects the addresses of nodes that it has provisioned and sends these addresses to the Primary Provisioner, when its address timer times out, which indicates the Temporary Provisioner hasn't provisioned any devices for 10s.
9. The Primary Provisioner reconnects to the Top Provisioner when its address timer times out, which indicates the Primary Provisioner hasn't received any messages from the Temporary Provisioners for 10s.
10. The Top Provisioner sends the `node_adress_Get` message automatically after reconnecting with the Primary Provisioner.
11. At this point, the Top Provisioner is able to control any nodes in the BLE Mesh Network.

> Note:
> 
> The nodes in the BLE Mesh Network only disable its provisioner functionality after it has been controlled by the Top Provisioner for at least one time.

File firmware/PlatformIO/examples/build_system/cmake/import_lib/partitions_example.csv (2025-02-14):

# Name | Type | SubType | Offset | Size | Flags
# Note: if you have increased the bootloader size | make sure to update the offsets to avoid overlap
nvs | data | nvs | 0x9000 | 0x6000
phy_init | data | phy | 0xf000 | 0x1000
factory | app | factory | 0x10000 | 1M
storage | data | fat |  | 528K

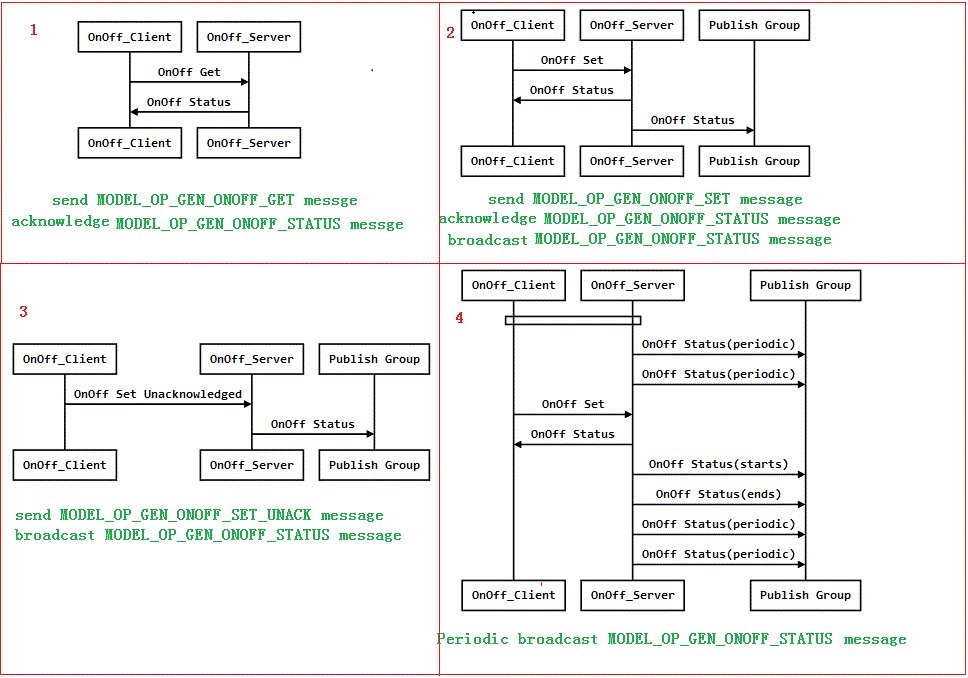
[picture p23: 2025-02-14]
firmware/PlatformIO/examples/bluetooth/esp_ble_mesh/onoff_models/onoff_client/tutorial/images/message.png

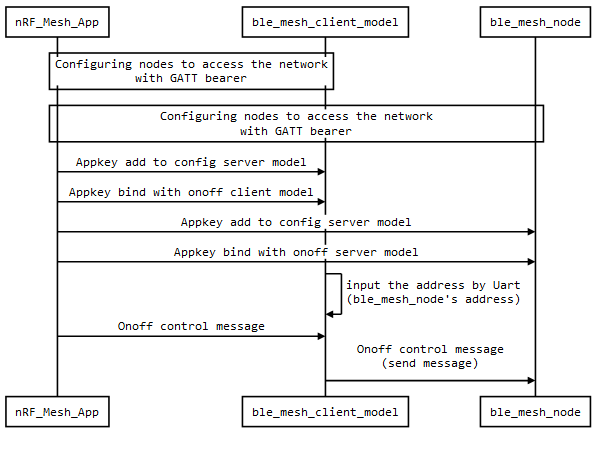
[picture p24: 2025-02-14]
firmware/PlatformIO/examples/bluetooth/esp_ble_mesh/onoff_models/onoff_client/tutorial/images/picture5.png

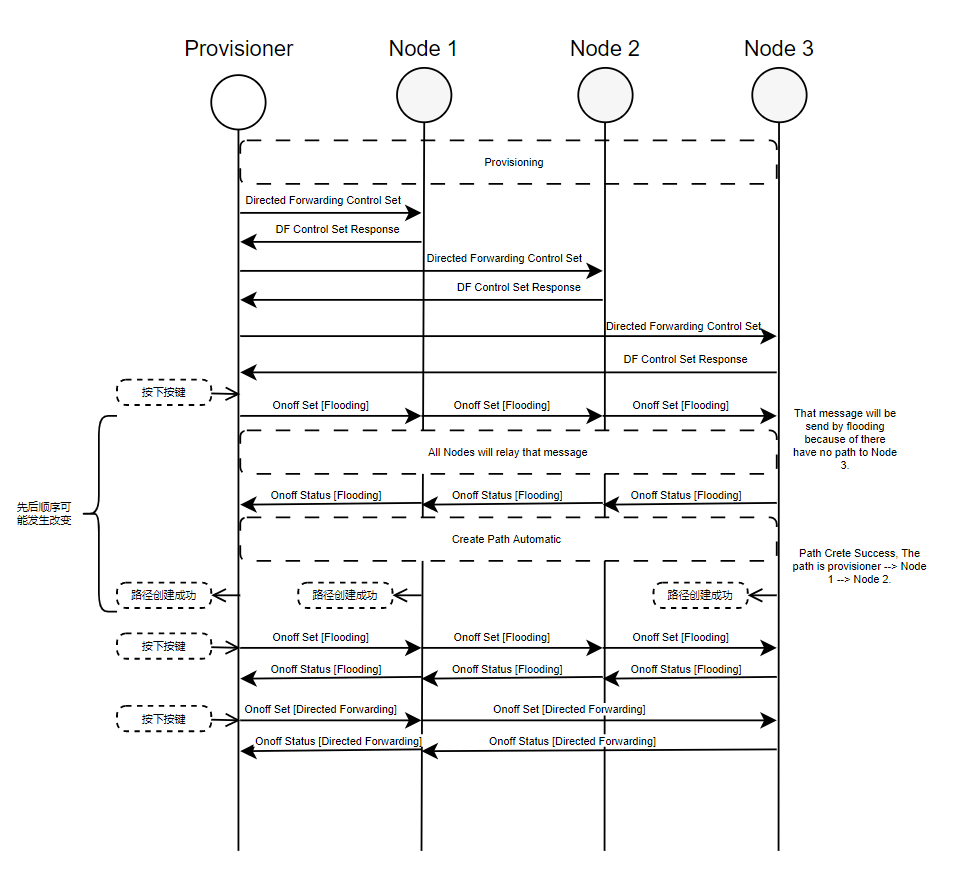
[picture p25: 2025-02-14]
firmware/PlatformIO/examples/bluetooth/esp_ble_mesh/directed_forwarding/tutorial/images/directed_forwarding_sequence.png

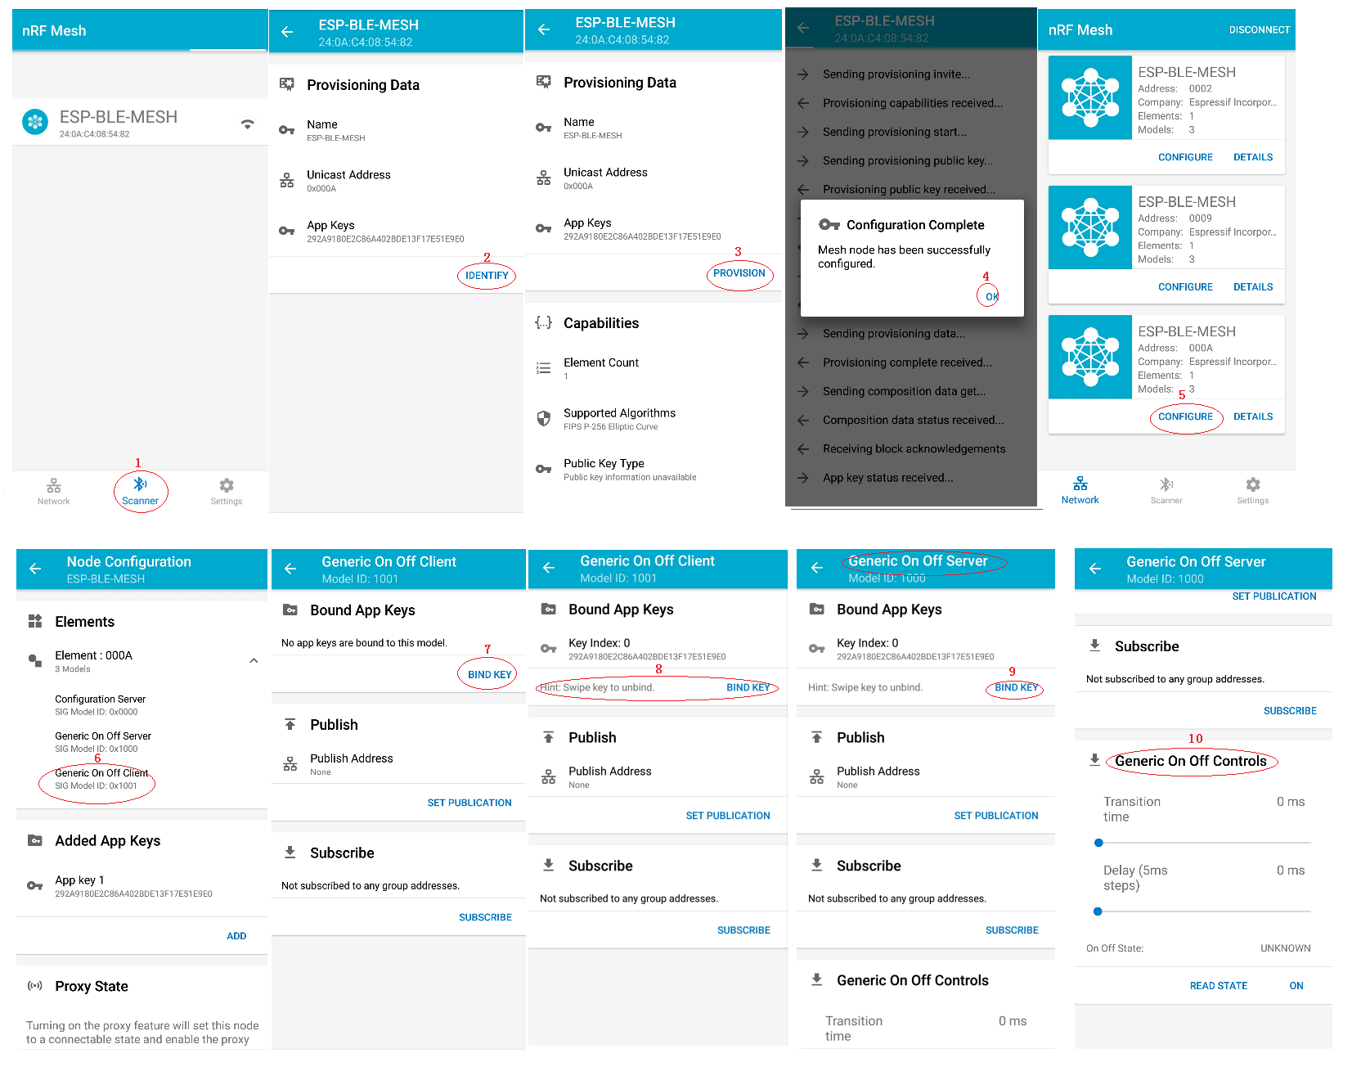
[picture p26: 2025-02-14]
firmware/PlatformIO/examples/bluetooth/esp_ble_mesh/onoff_models/onoff_client/tutorial/images/app.png

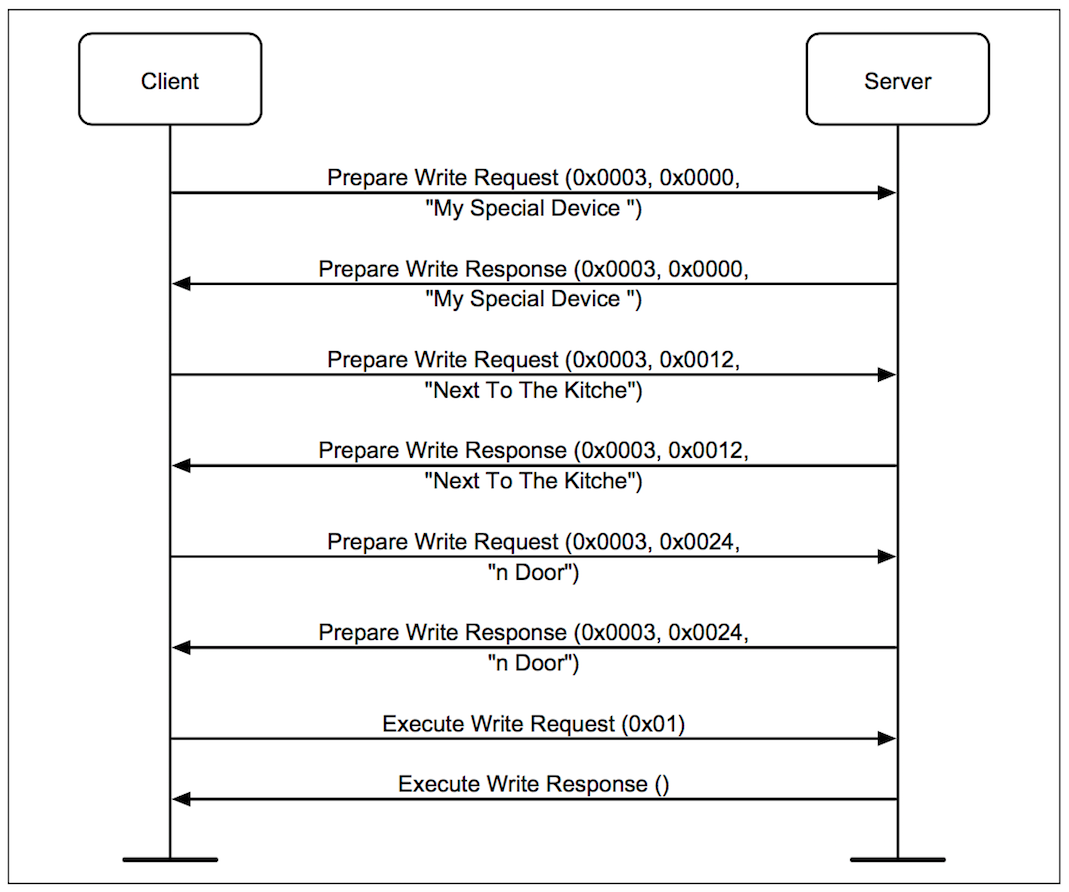
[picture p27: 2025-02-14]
firmware/PlatformIO/examples/bluetooth/bluedroid/ble/gatt_server/tutorial/image/GATT_Server_Figure_2.png

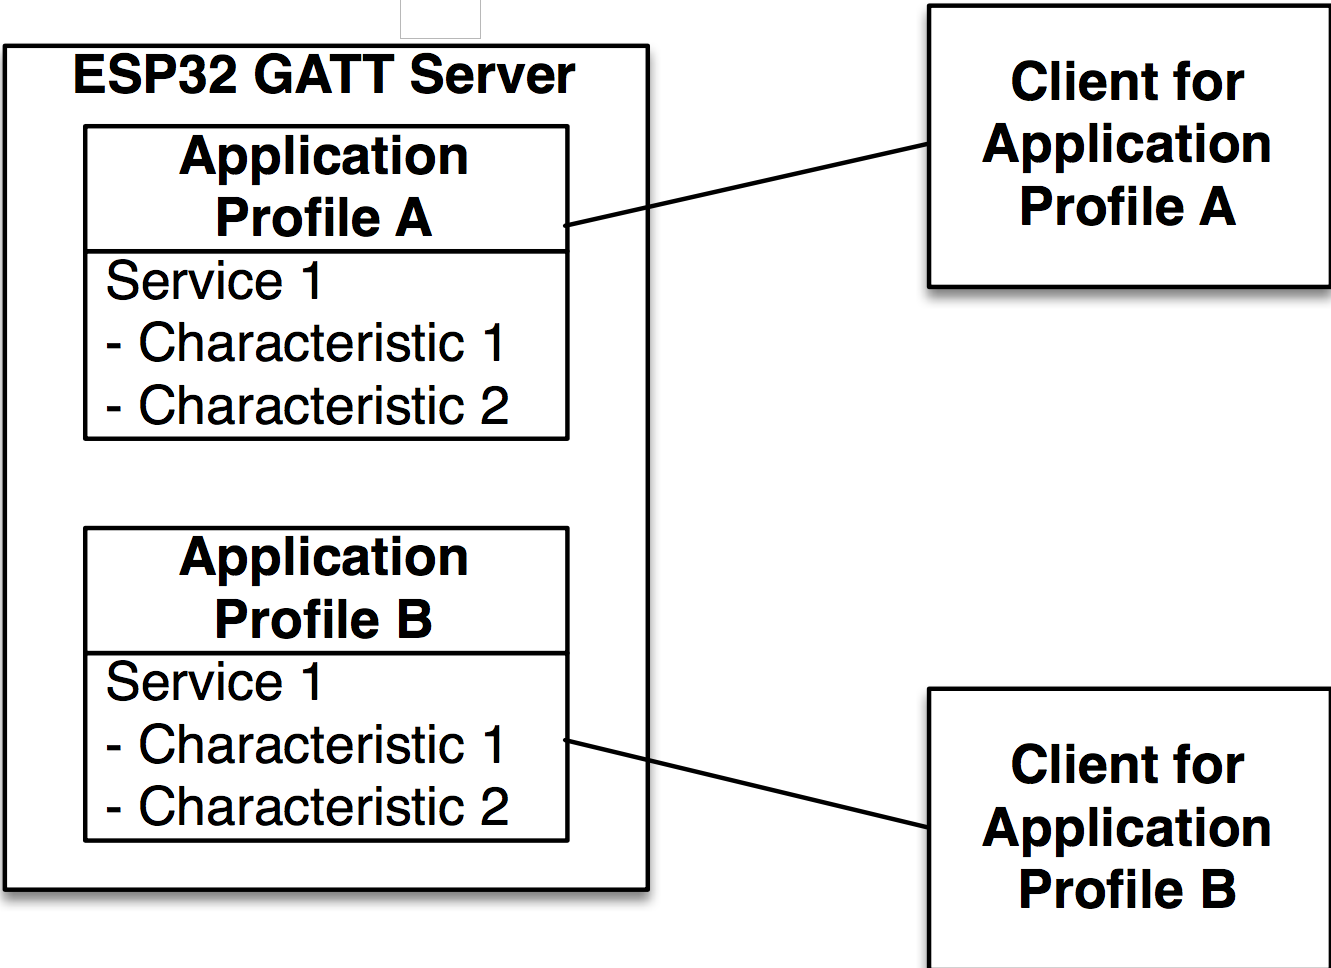
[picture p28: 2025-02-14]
firmware/PlatformIO/examples/bluetooth/bluedroid/ble/gatt_server/tutorial/image/GATT_Server_Figure_1.png

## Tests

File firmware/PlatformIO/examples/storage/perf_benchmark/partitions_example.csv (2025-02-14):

# Name | Type | SubType | Offset | Size | Flags
nvs | data | nvs |  | 0x6000
phy_init | data | phy |  | 0x1000
factory | app | factory |  | 1M
storage | data | undefined |  | 2M

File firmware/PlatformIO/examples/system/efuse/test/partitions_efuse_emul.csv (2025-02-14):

# Name | Type | SubType | Offset | Size | Flags
bootloader | bootloader | primary | N/A | N/A
partition_table | partition_table | primary | N/A | N/A
nvs | data | nvs |  | 0x4000
phy_init | data | phy |  | 0x1000
storage | data | 0xff |  | 0x1000 | encrypted
nvs_key | data | nvs_keys |  | 0x1000 | encrypted
emul_efuse | data | efuse |  | 0x2000
factory | app | factory |  | 1M

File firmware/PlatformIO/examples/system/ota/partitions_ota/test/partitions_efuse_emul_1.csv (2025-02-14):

# Name | Type | SubType | Offset | Size | Flags
nvs | data | nvs |  | 0x6000
nvs_key | data | nvs_keys |  | 4K
storage | data |  |  | 0x1000 | encrypted
otadata | data | ota |  | 0x2000
phy_init | data | phy |  | 0x1000
emul_efuse | data | efuse |  | 0x2000
ota_0 | app | ota_0 |  | 0x1B0000
ota_1 | app | ota_1 |  | 0x1B0000

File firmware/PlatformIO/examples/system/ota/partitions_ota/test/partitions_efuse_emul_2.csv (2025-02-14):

# Name | Type | SubType | Offset | Size | Flags
PrimaryBTLDR | bootloader | primary | N/A | N/A
PrimaryPrtTable | partition_table | primary | N/A | N/A
nvs | data | nvs |  | 0x6000
nvs_key | data | nvs_keys |  | 4K
storage | data |  |  | 0x1000 | encrypted
otadata | data | ota |  | 0x2000
phy_init | data | phy |  | 0x1000
emul_efuse | data | efuse |  | 0x2000
ota_0 | app | ota_0 |  | 0x1B0000
ota_1 | app | ota_1 |  | 0x1B0000

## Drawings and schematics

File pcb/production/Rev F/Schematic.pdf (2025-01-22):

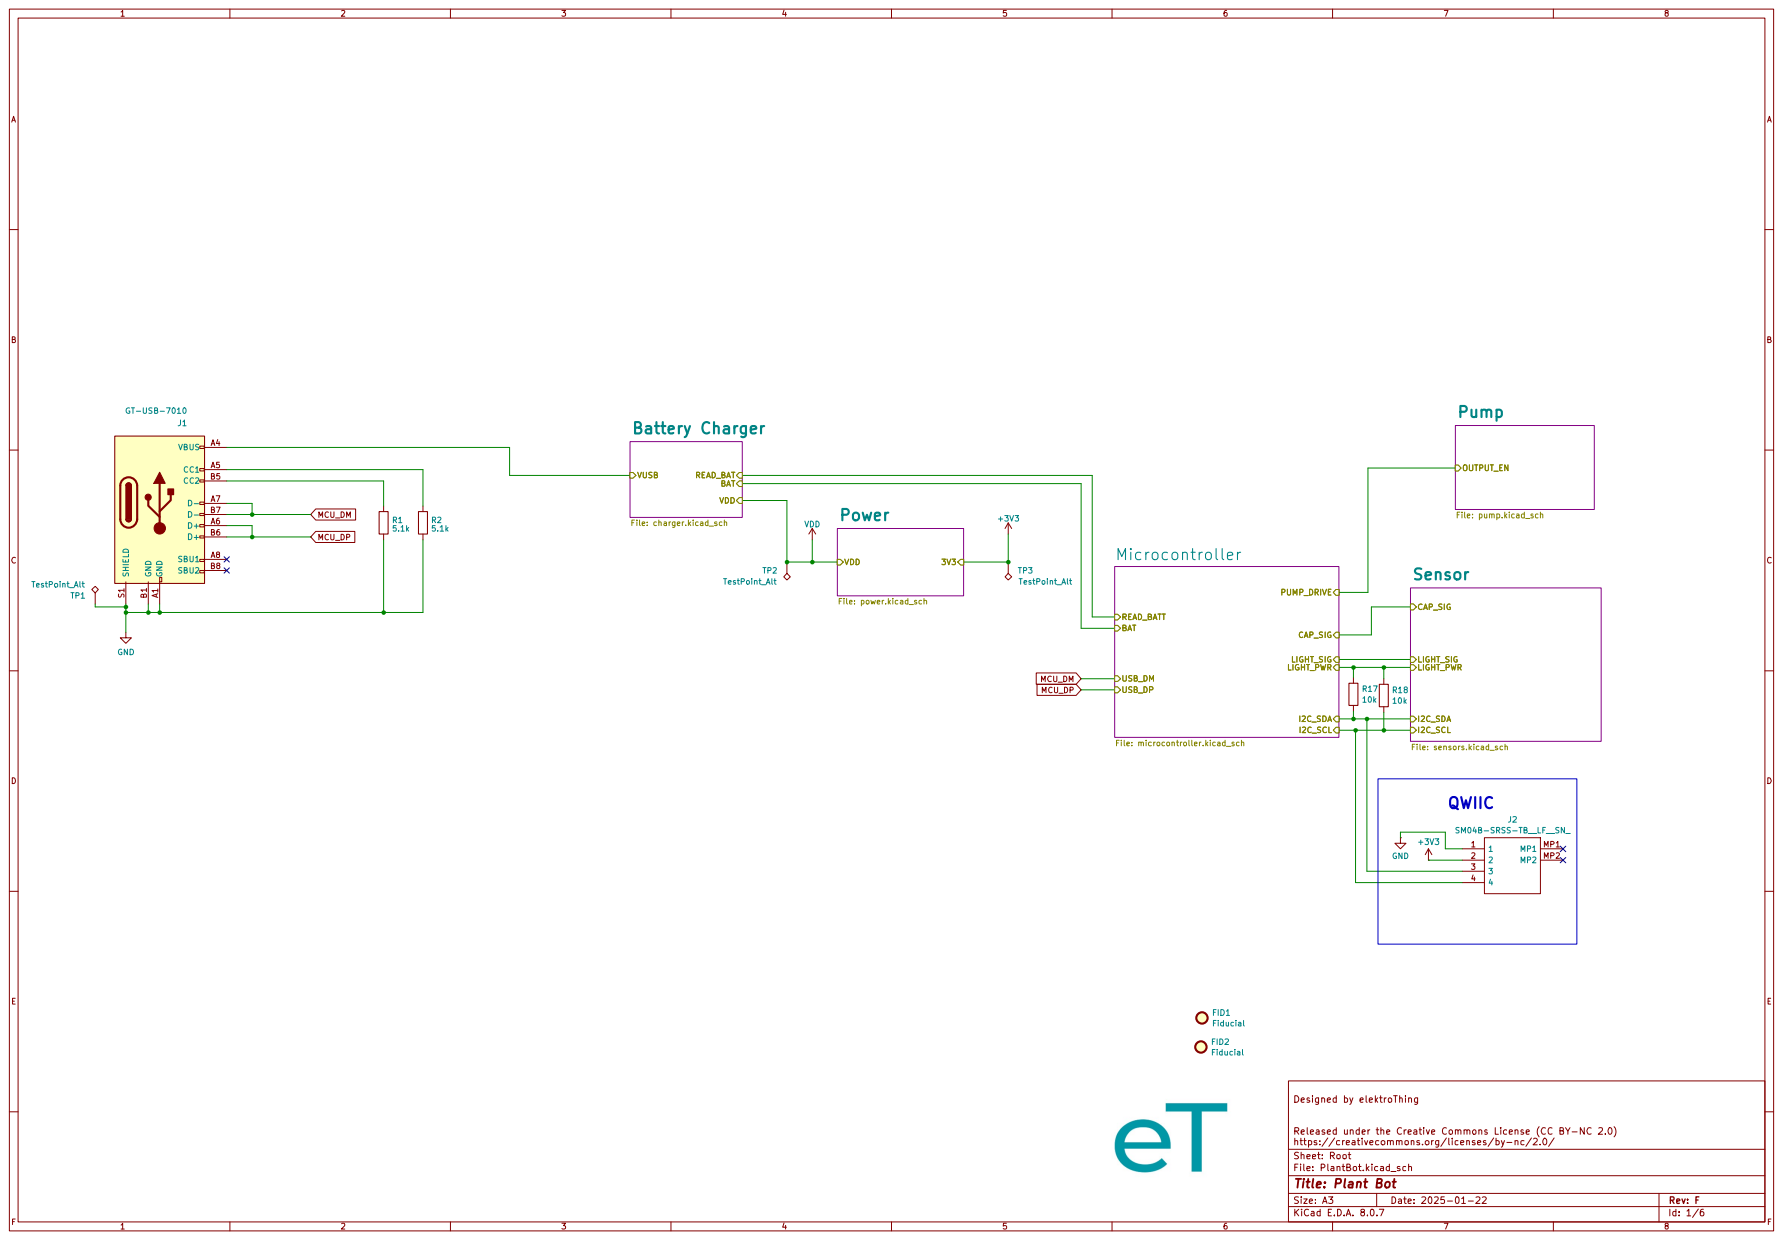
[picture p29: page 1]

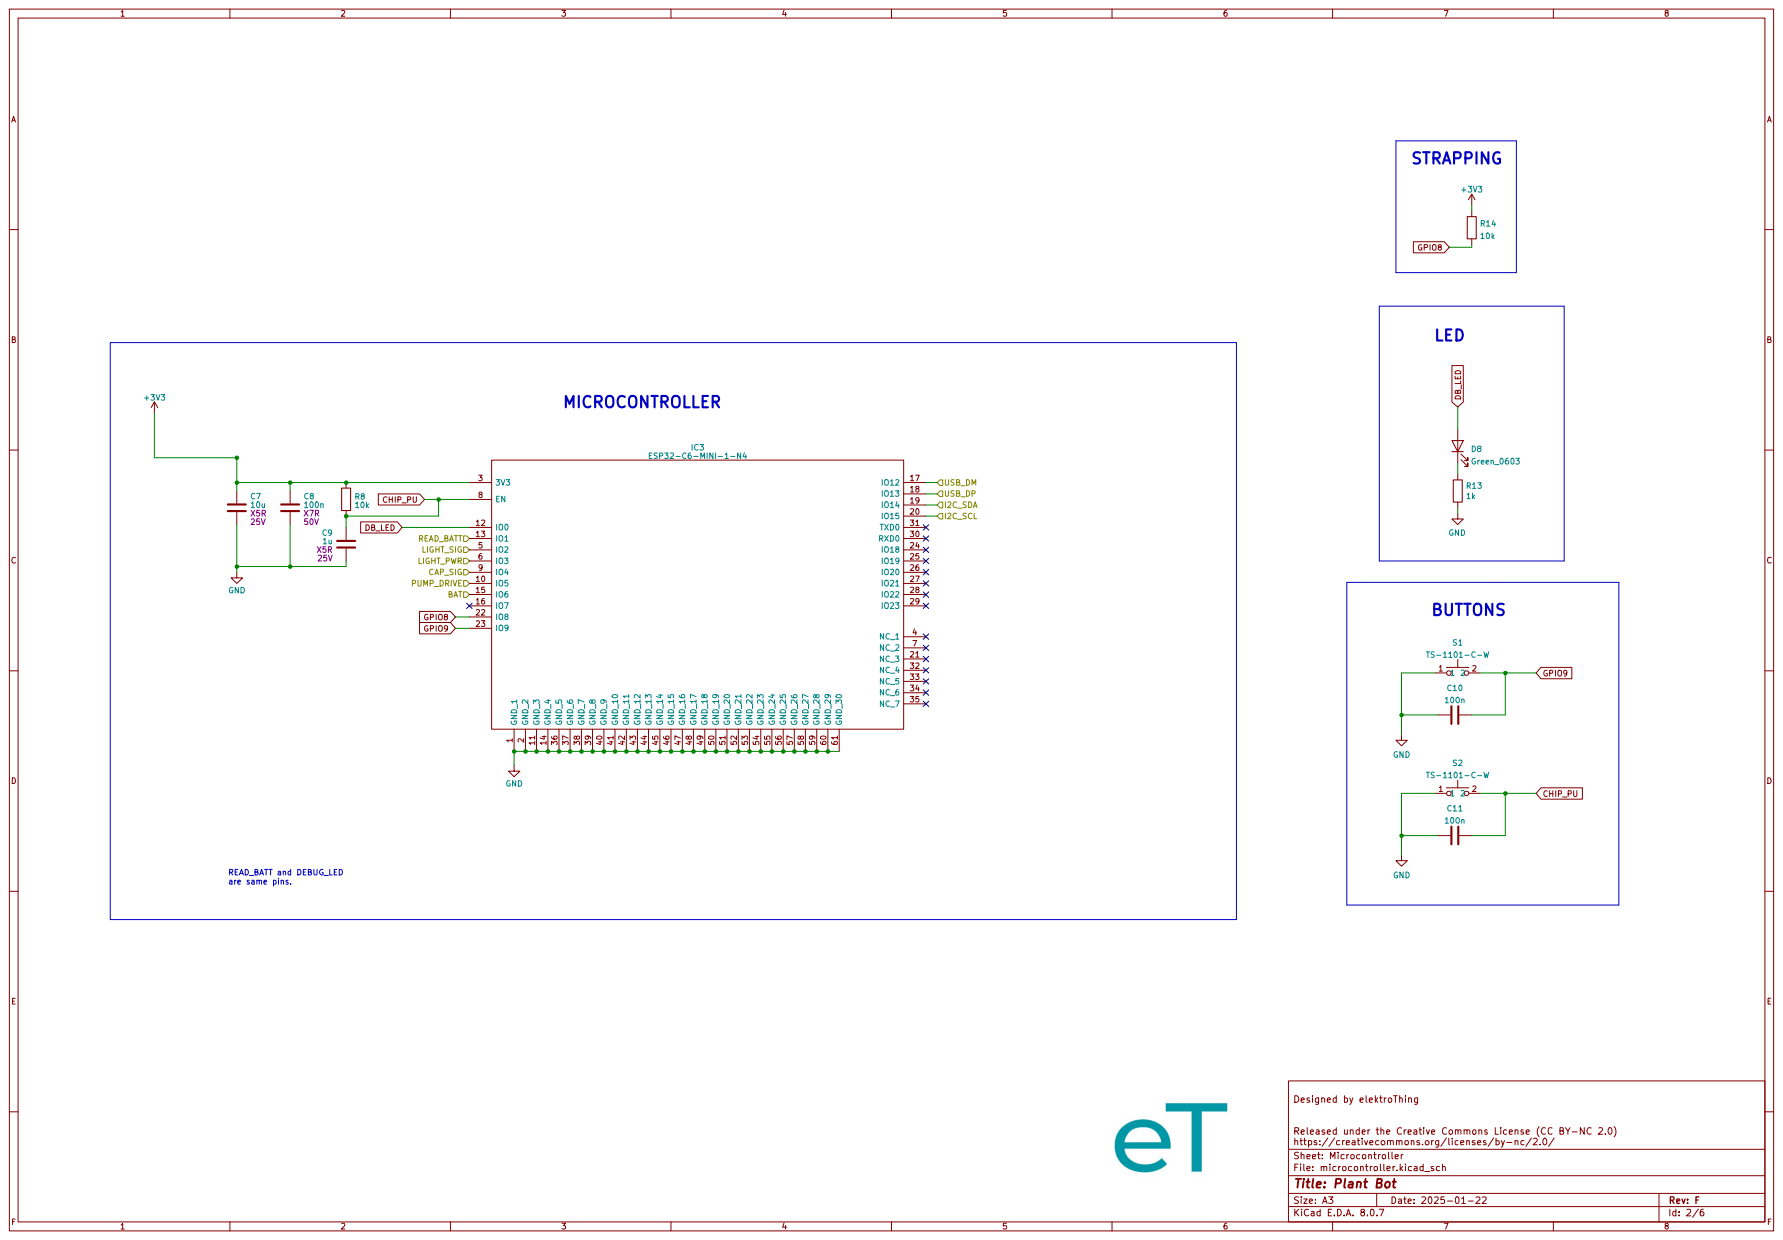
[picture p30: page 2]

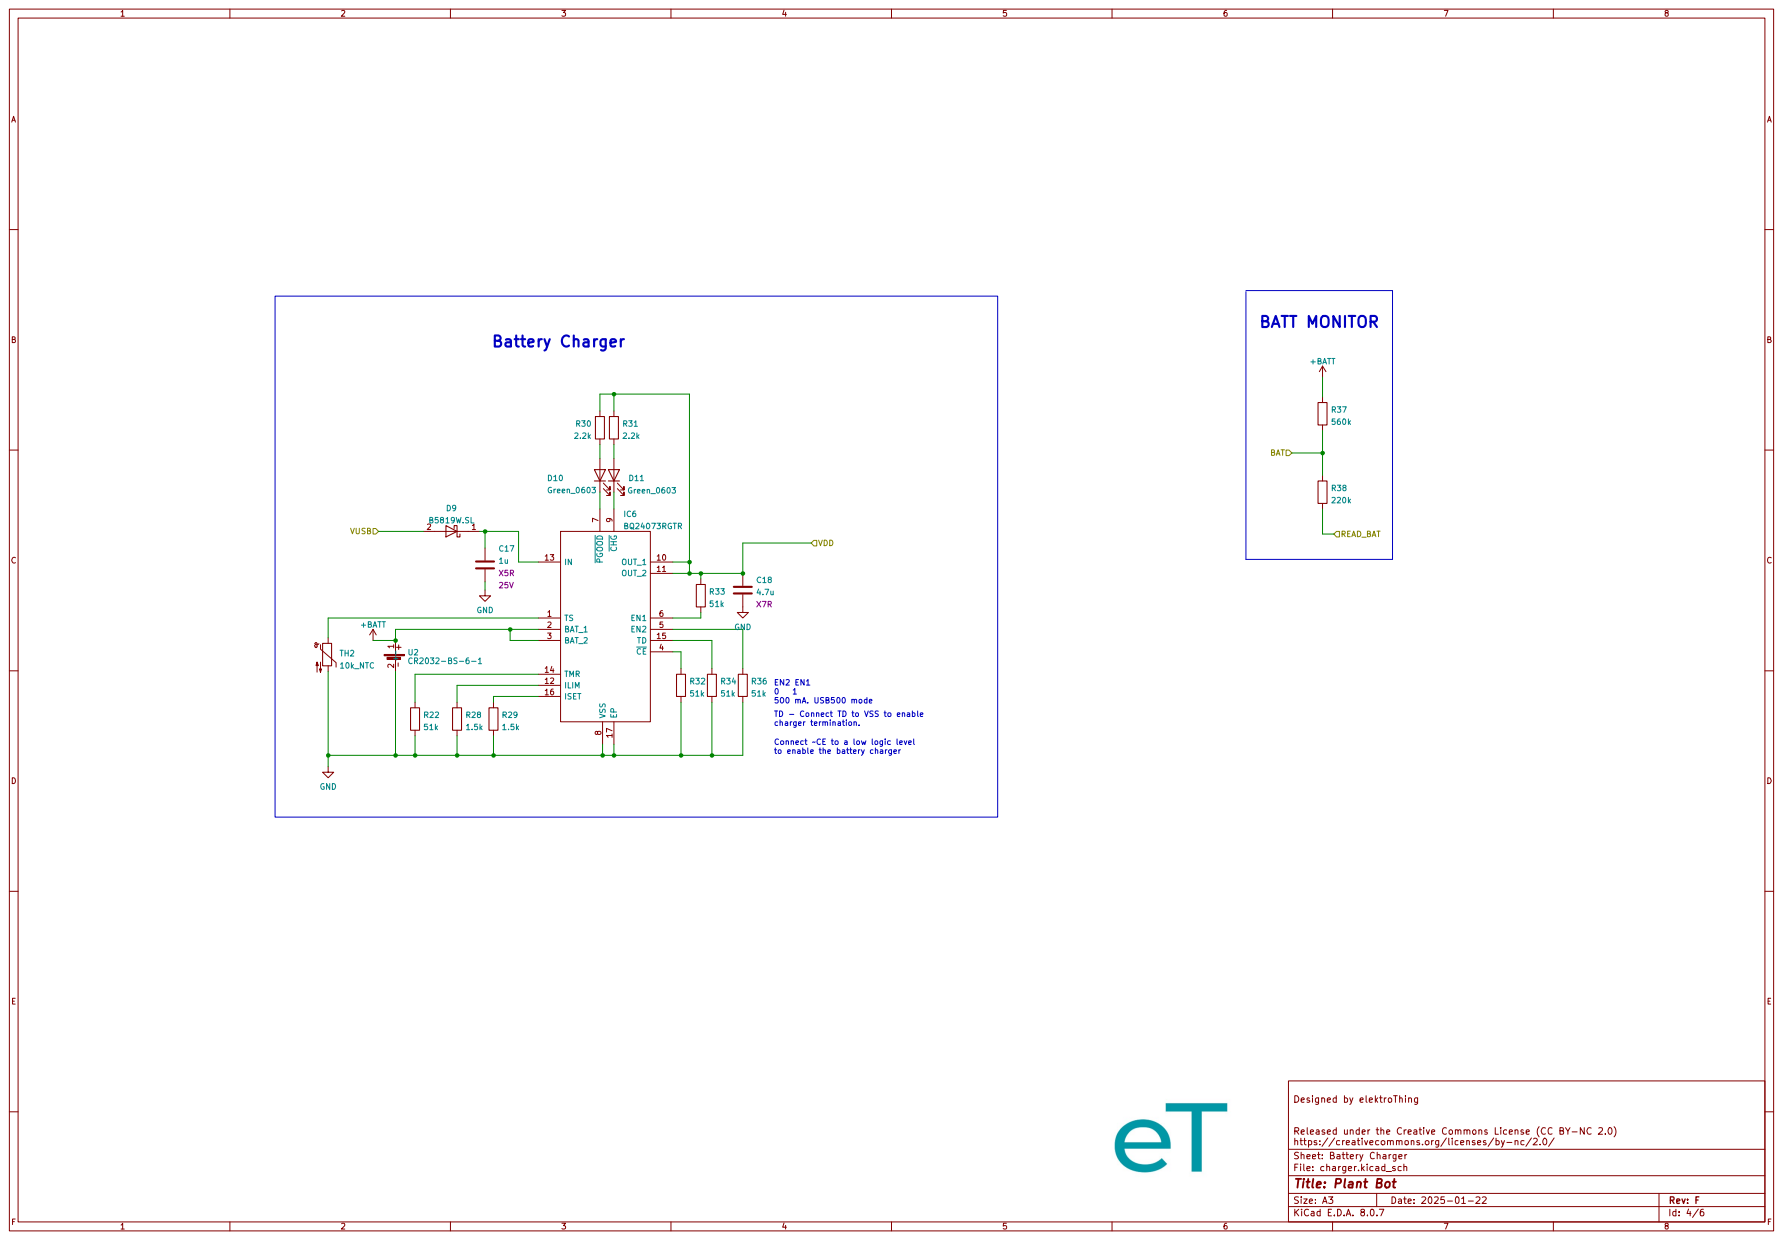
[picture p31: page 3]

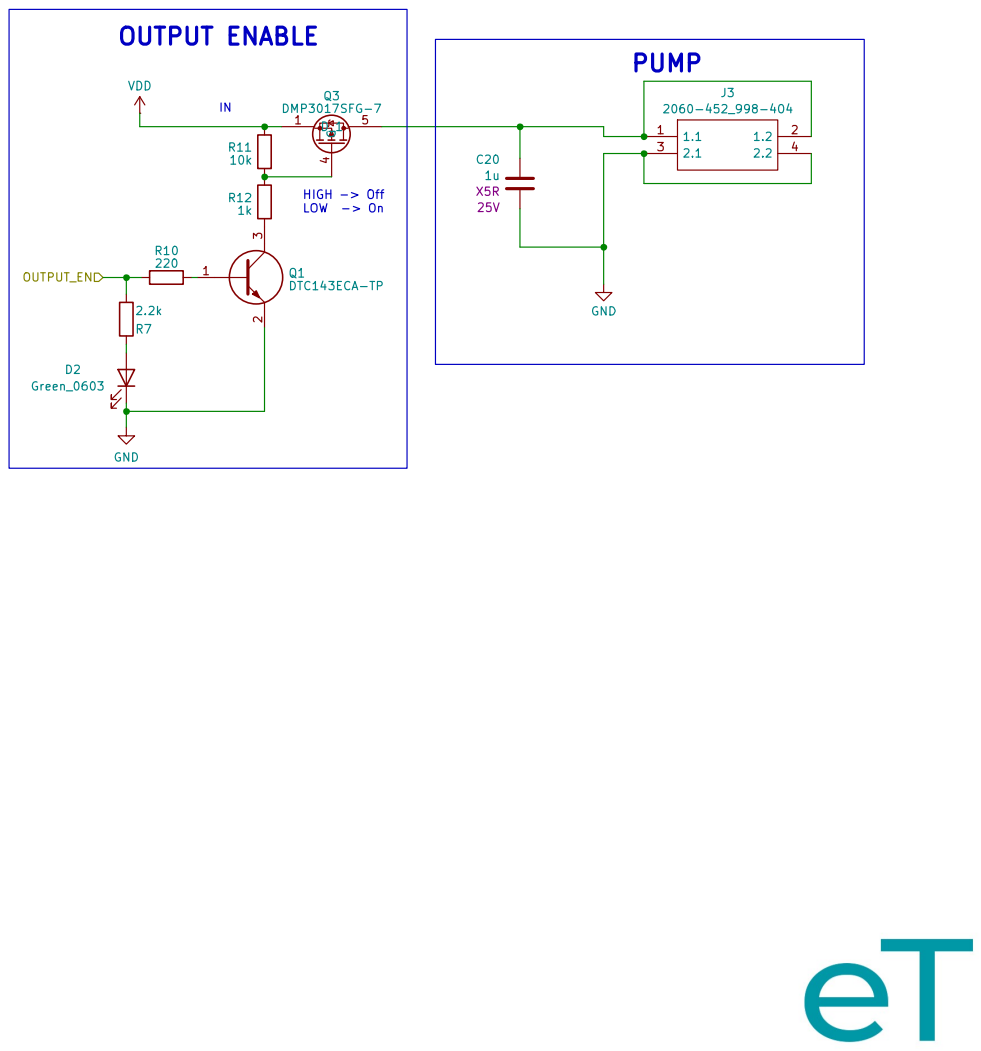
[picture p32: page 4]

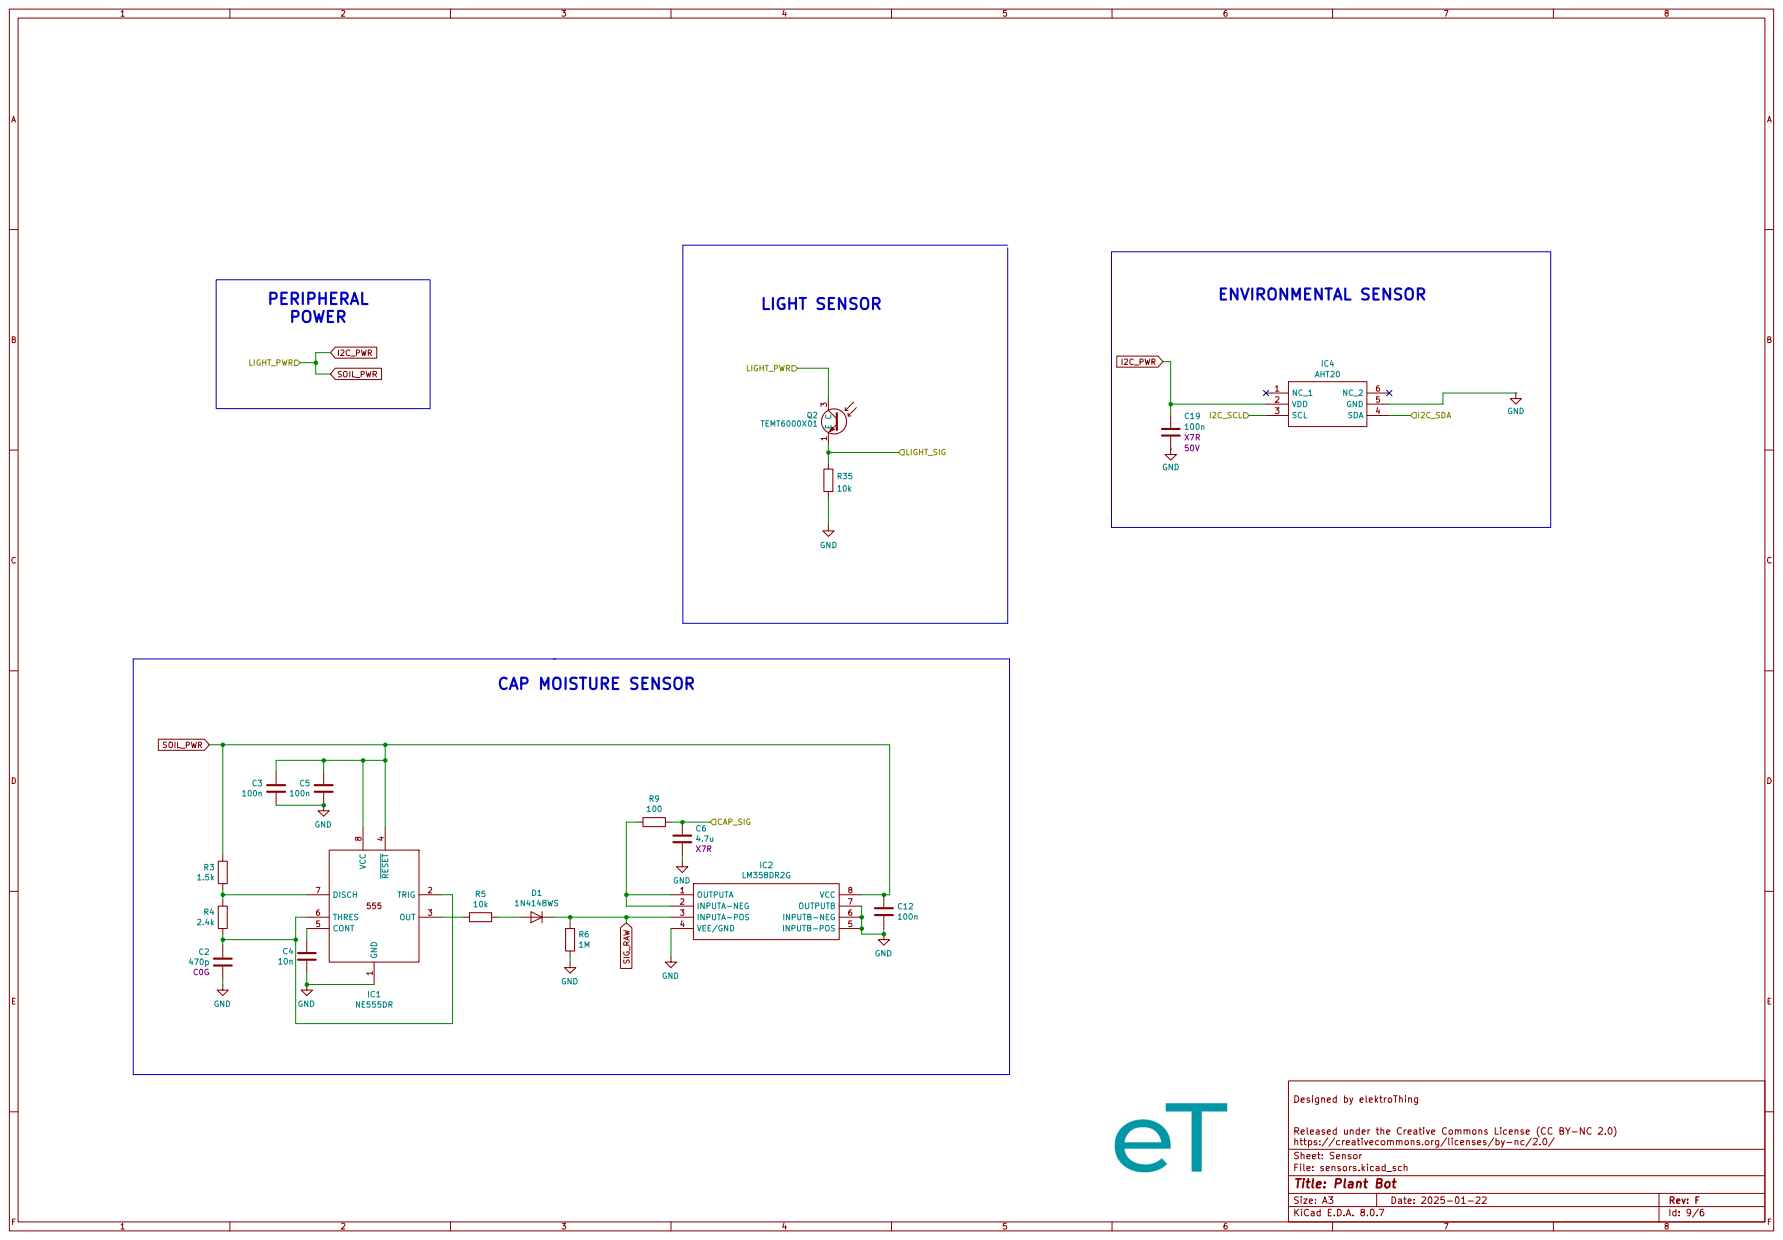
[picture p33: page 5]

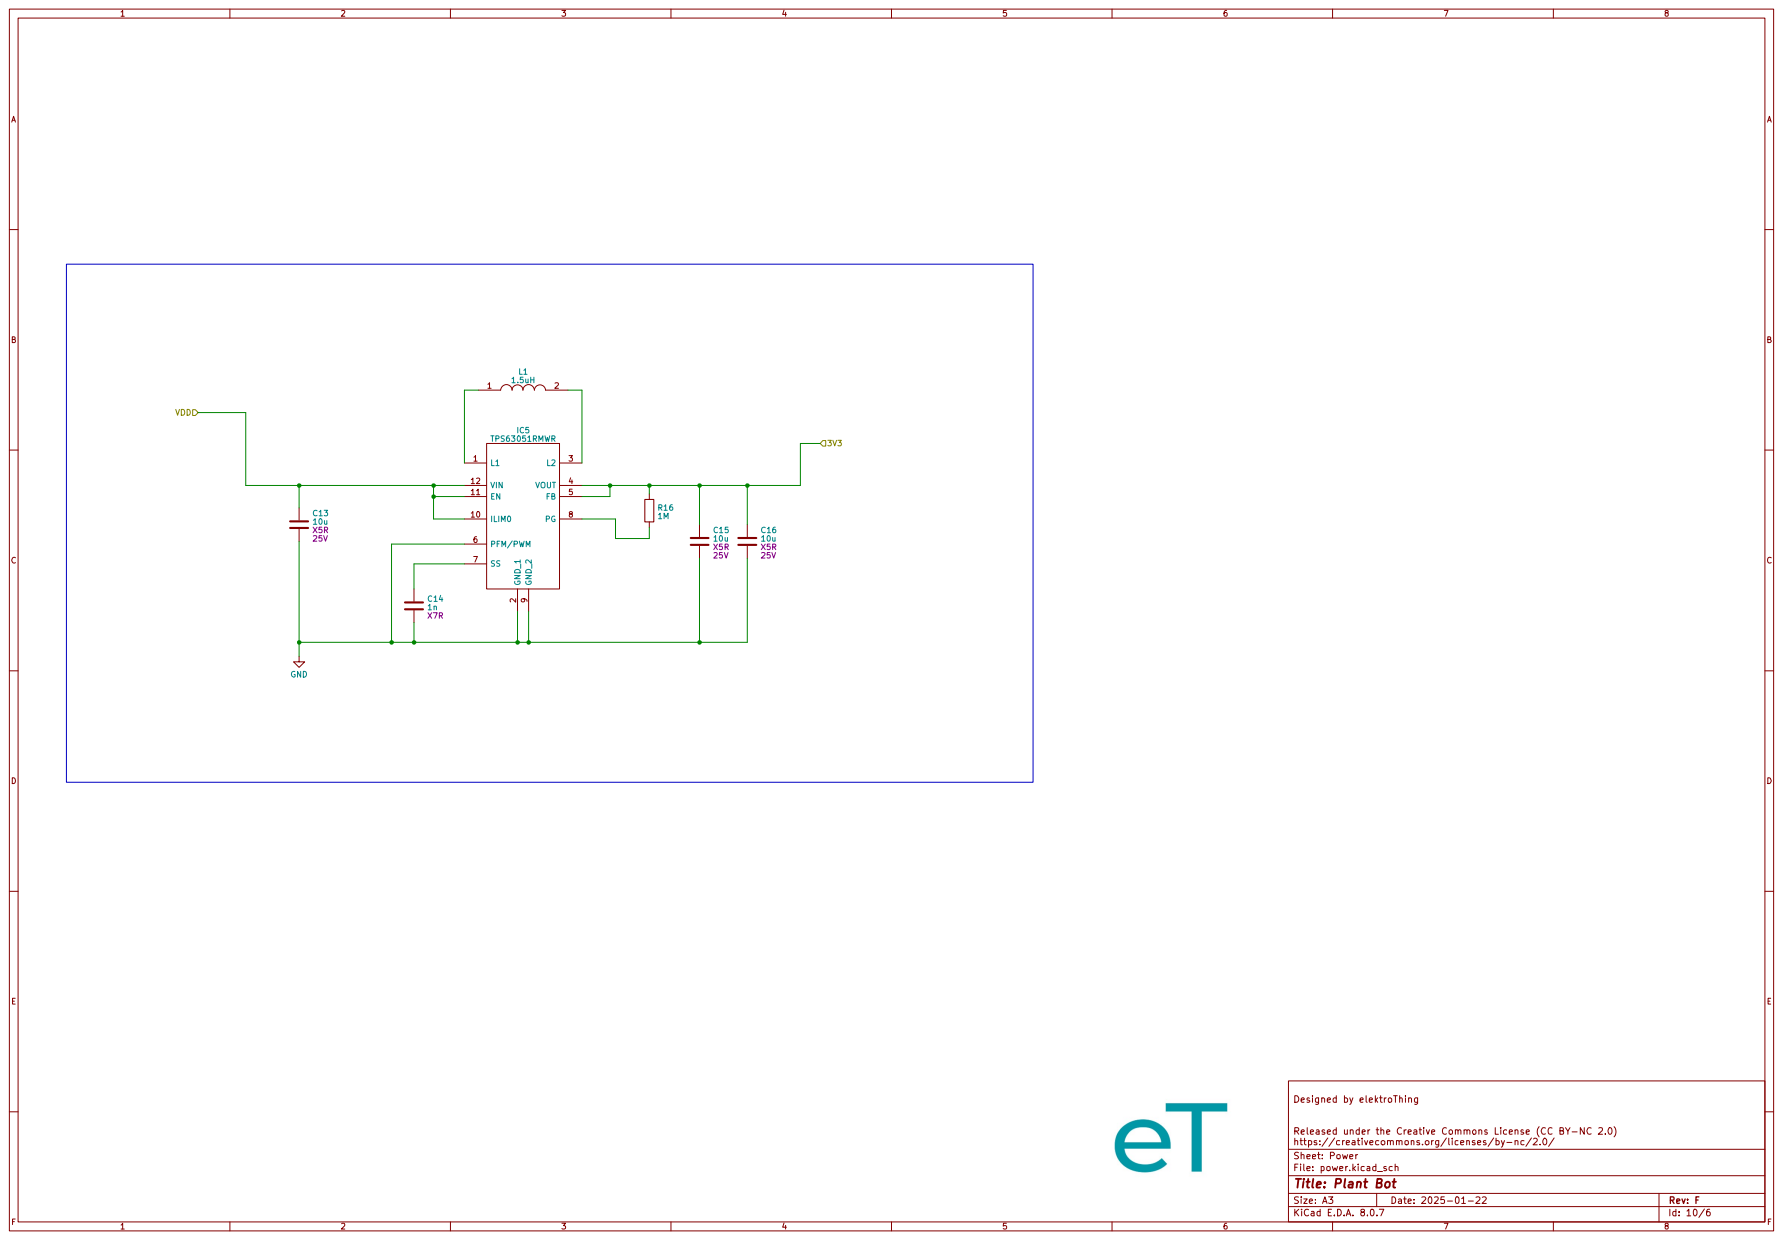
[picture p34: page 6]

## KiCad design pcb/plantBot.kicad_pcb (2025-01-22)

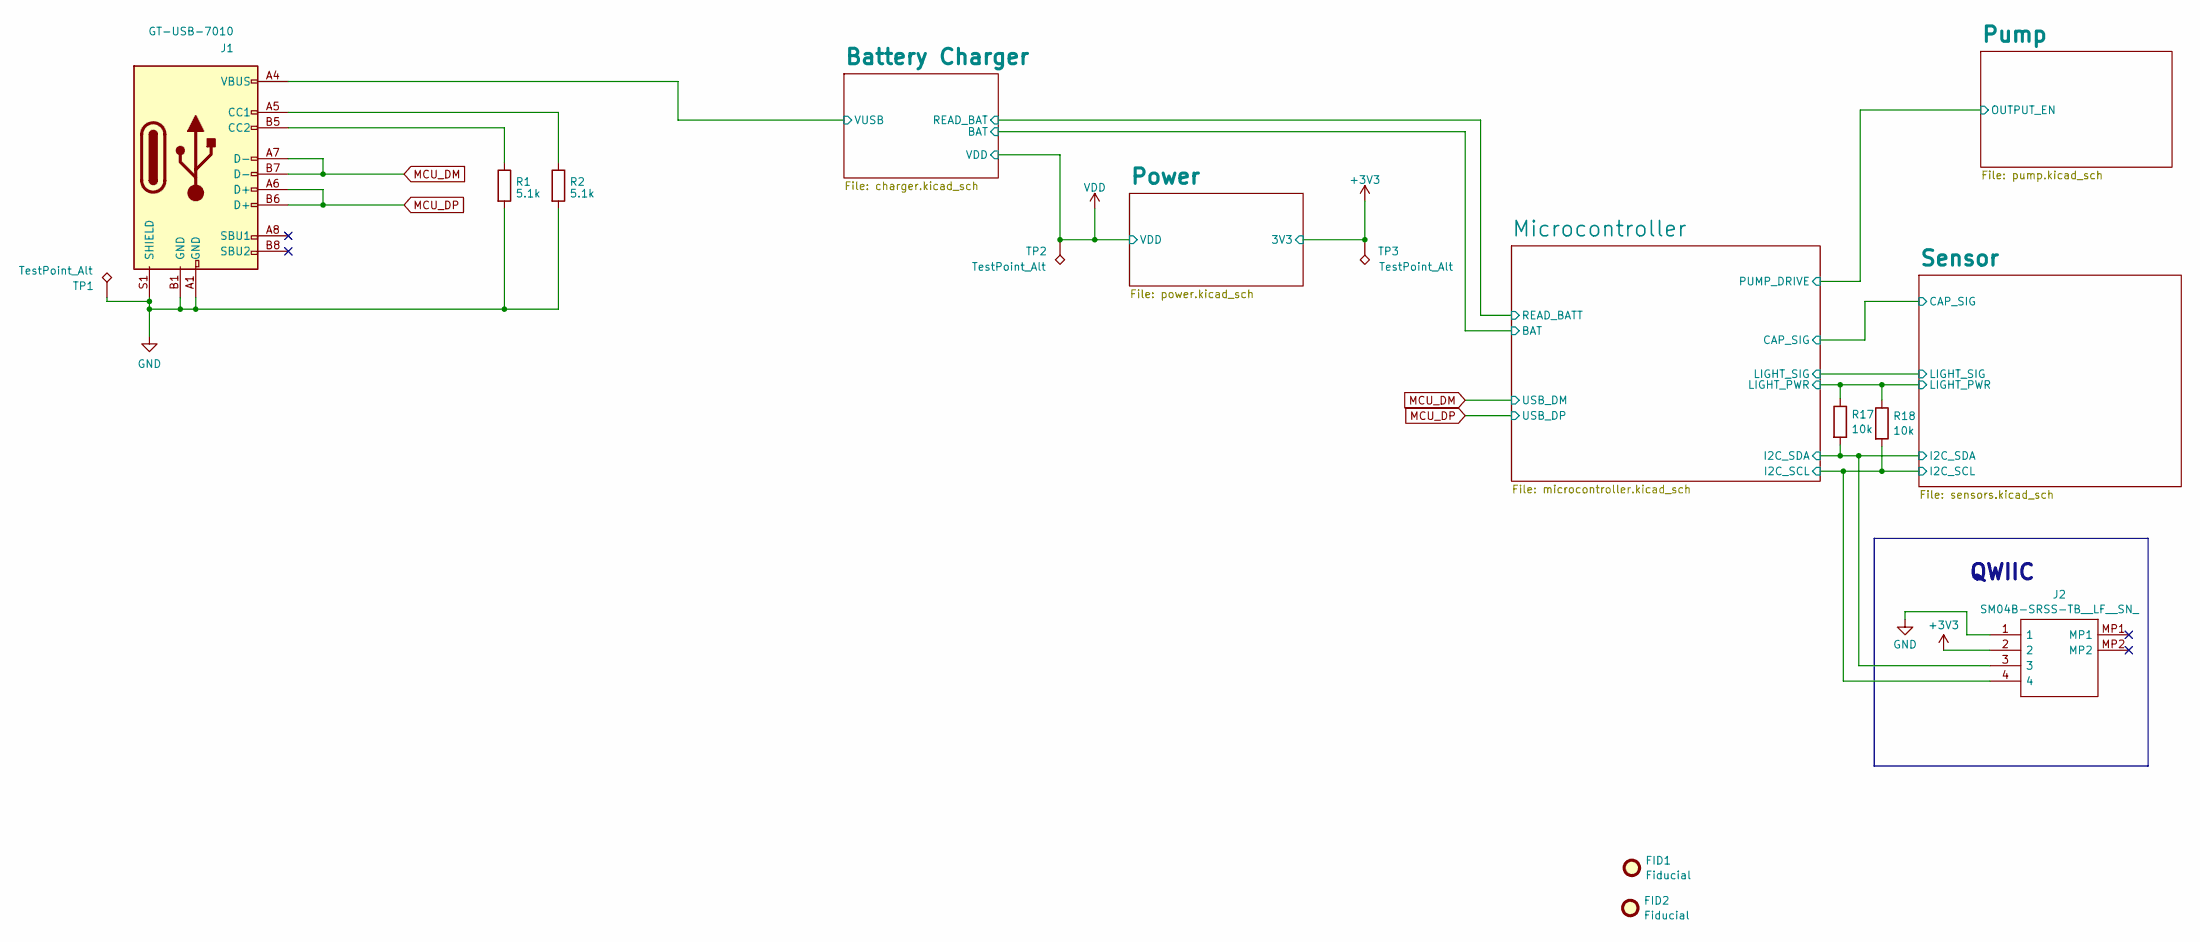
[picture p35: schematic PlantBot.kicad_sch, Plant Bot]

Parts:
FID1: Fiducial; Product Stamp
FID2: Fiducial; jlcpcb_logo_2mm
J1: GT-USB-7010; GT-USB-7010A; LCSC C963370
J2: SM04B-SRSS-TB__LF__SN_; SM04BSRSSTBLFSN; Manufacturer_Part_Number SM04B-SRSS-TB (LF)(SN); LCSC C160404
R1, R2: 5.1k; R_0402_1005Metric; LCSC C2906948
R17, R18: 10k; R_0402_1005Metric; LCSC C25744
TP1, TP2, TP3: TestPoint_Alt; TestPoint_Pad_1.0x1.0mm

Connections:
+3V3: J2.2, TP3.1; also elsewhere on the board
/Battery Charger/VUSB: J1.A4 (VBUS), J1.A9 (VBUS), J1.B4 (VBUS), J1.B9 (VBUS); also elsewhere on the board
/Microcontroller/I2C_SCL: J2.4, R18.2; also elsewhere on the board
/Microcontroller/I2C_SDA: J2.3, R17.2; also elsewhere on the board
GND: J1.A1 (GND), J1.B1 (GND), J1.S1 (SHIELD), J2.1, R1.2, R2.2, TP1.1; also elsewhere on the board
I2C_PWR: R17.1, R18.1; also elsewhere on the board
MCU_DM: J1.A7 (D-), J1.B7 (D-); also elsewhere on the board
MCU_DP: J1.A6 (D+), J1.B6 (D+); also elsewhere on the board
unnamed: J1.A5 (CC1), R2.1
unnamed: J1.B5 (CC2), R1.1
VDD: TP2.1; also elsewhere on the board

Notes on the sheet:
QWIIC

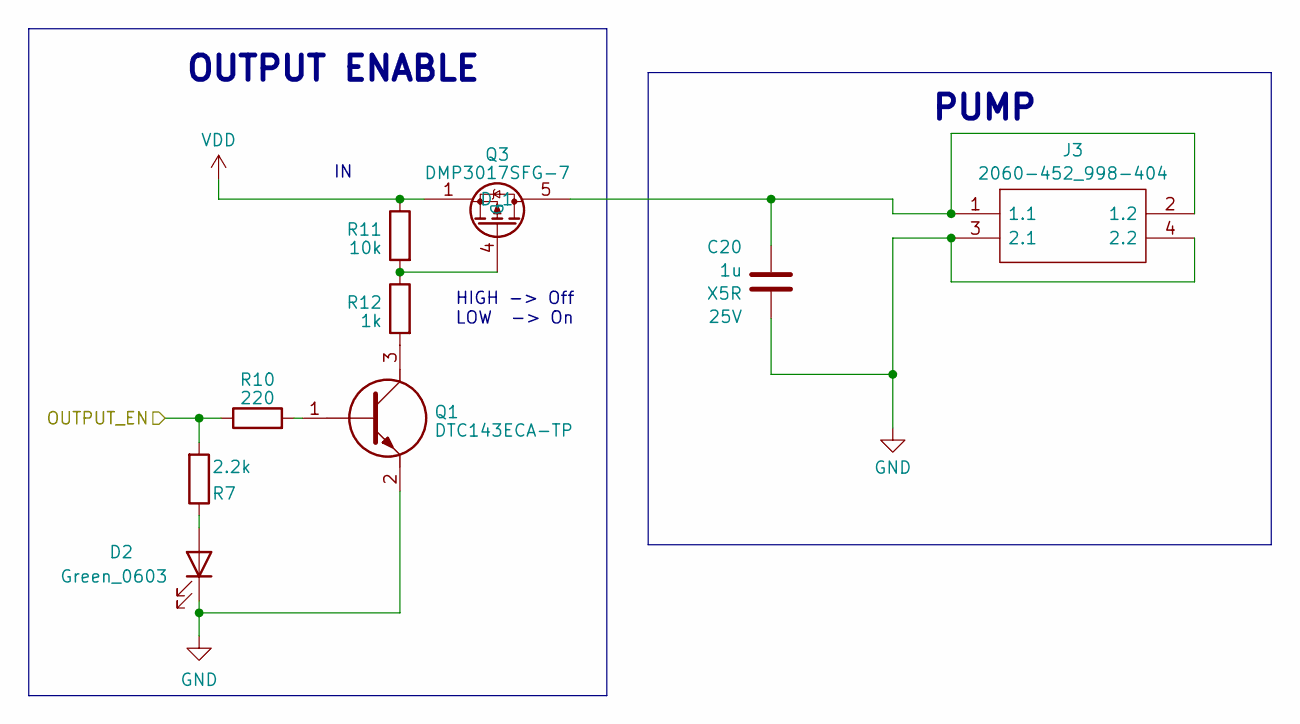
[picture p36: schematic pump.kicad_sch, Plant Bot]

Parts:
C20: 1u; C_0402_1005Metric; Voltage 25V; LCSC C52923
D2: Green_0603; LED_0603_1608Metric; LCSC C72043
J3: 2060-452_998-404; 2060452998404; Manufacturer_Part_Number 2060-452/998-404; LCSC C2765055
Q1: DTC143ECA-TP; SOT95P237X125-3N; Manufacturer_Part_Number DTC143ECA-TP; Mouser Part Number 833-DTC143ECA-TP
Q3: DMP3017SFG-7; DMP3007SFG7; Manufacturer_Part_Number DMP3017SFG-7; Mouser Part Number 621-DMP3017SFG-7
R7: 2.2k; R_0402_1005Metric; LCSC C25879
R10: 220; R_0402_1005Metric; LCSC C25091
R11: 10k; R_0402_1005Metric; LCSC C25744
R12: 1k; R_0402_1005Metric; LCSC C11702

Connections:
/Microcontroller/PUMP_DRIVE: R7.2, R10.1; also elsewhere on the board
GND: C20.2, D2.1 (K), J3.3 (2.1), J3.4 (2.2), Q1.2; also elsewhere on the board
unnamed: D2.2 (A), R7.1
unnamed: C20.1, J3.1 (1.1), J3.2 (1.2), Q3.5 (D_1), Q3.6, Q3.7, Q3.8, Q3.9
unnamed: Q1.1, R10.2
unnamed: Q1.3, R12.2
unnamed: Q3.4 (G), R11.2, R12.1
VDD: Q3.1, Q3.2, Q3.3, R11.1; also elsewhere on the board

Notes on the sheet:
OUTPUT ENABLE
PUMP
HIGH -> Off LOW -> On

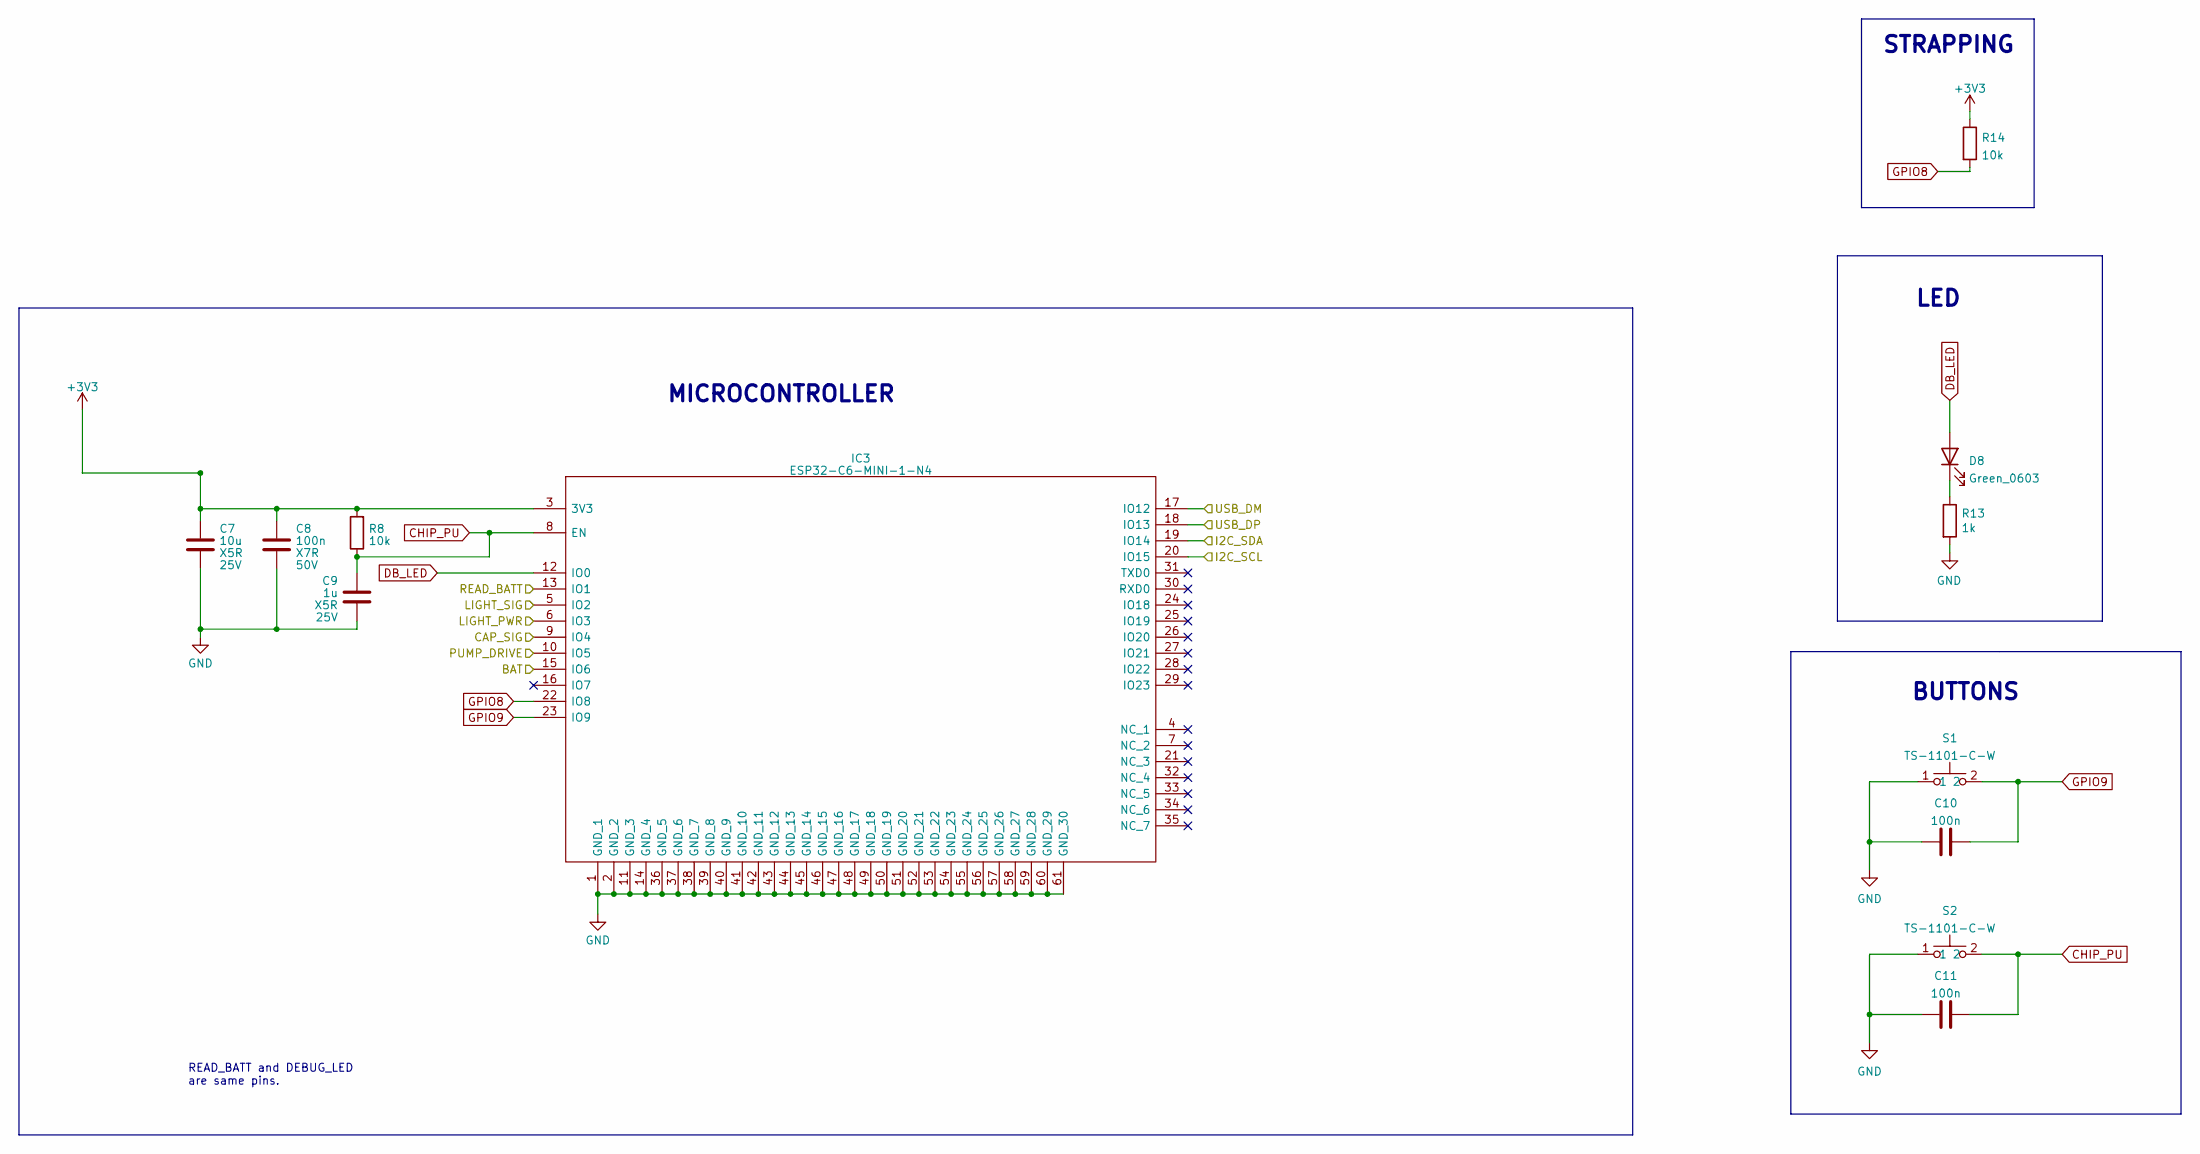
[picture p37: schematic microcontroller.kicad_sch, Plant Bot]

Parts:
C7: 10u; C_0805_2012Metric; Voltage 25V; LCSC C15850
C8: 100n; C_0402_1005Metric; Voltage 50V; LCSC C307331
C9: 1u; C_0402_1005Metric; Voltage 25V; LCSC C52923
C10, C11: 100n; C_0402_1005Metric; LCSC C307331
D8: Green_0603; LED_0603_1608Metric; LCSC C72043
IC3: ESP32-C6-MINI-1-N4; ESP32C6MINI1N4; Manufacturer_Part_Number ESP32-C6-MINI-1-N4; Mouser Part Number 356-ESP32C6MINI-1-N4
R8, R14: 10k; R_0402_1005Metric; LCSC C25744
R13: 1k; R_0402_1005Metric; LCSC C11702
S1, S2: TS-1101-C-W; TS1101CW; Manufacturer_Part_Number TS-1101-C-W; LCSC C318938

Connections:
+3V3: C7.1, C8.1, IC3.3 (3V3), R8.2, R14.1; also elsewhere on the board
/Battery Charger/BAT: IC3.15 (IO6); also elsewhere on the board
/Battery Charger/READ_BAT: IC3.13 (IO1); also elsewhere on the board
/Microcontroller/CAP_SIG: IC3.9 (IO4); also elsewhere on the board
/Microcontroller/I2C_SCL: IC3.20 (IO15); also elsewhere on the board
/Microcontroller/I2C_SDA: IC3.19 (IO14); also elsewhere on the board
/Microcontroller/LIGHT_SIG: IC3.5 (IO2); also elsewhere on the board
/Microcontroller/PUMP_DRIVE: IC3.10 (IO5); also elsewhere on the board
CHIP_PU: C9.2, C11.2, IC3.8 (EN), R8.1, S2.2
DB_LED: D8.2 (A), IC3.12 (IO0)
GND: C7.2, C8.2, C9.1, C10.1, C11.1, IC3.1 (GND_1), IC3.2 (GND_2), IC3.11 (GND_3), IC3.14 (GND_4), IC3.36 (GND_5), IC3.37 (GND_6), IC3.38 (GND_7), IC3.39 (GND_8), IC3.40 (GND_9), IC3.41 (GND_10), IC3.42 (GND_11), IC3.43 (GND_12), IC3.44 (GND_13), IC3.45 (GND_14), IC3.46 (GND_15), IC3.47 (GND_16), IC3.48 (GND_17), IC3.49 (GND_18), IC3.50 (GND_19), IC3.51 (GND_20), IC3.52 (GND_21), IC3.53 (GND_22), IC3.54 (GND_23), IC3.55 (GND_24), IC3.56 (GND_25), IC3.57 (GND_26), IC3.58 (GND_27), IC3.59 (GND_28), IC3.60 (GND_29), IC3.61 (GND_30), R13.2, S1.1, S2.1; also elsewhere on the board
GPIO8: IC3.22 (IO8), R14.2
GPIO9: C10.2, IC3.23 (IO9), S1.2
I2C_PWR: IC3.6 (IO3); also elsewhere on the board
MCU_DM: IC3.17 (IO12); also elsewhere on the board
MCU_DP: IC3.18 (IO13); also elsewhere on the board
unnamed: D8.1 (K), R13.1

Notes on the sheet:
STRAPPING
READ_BATT and DEBUG_LED are same pins.
LED
MICROCONTROLLER
BUTTONS

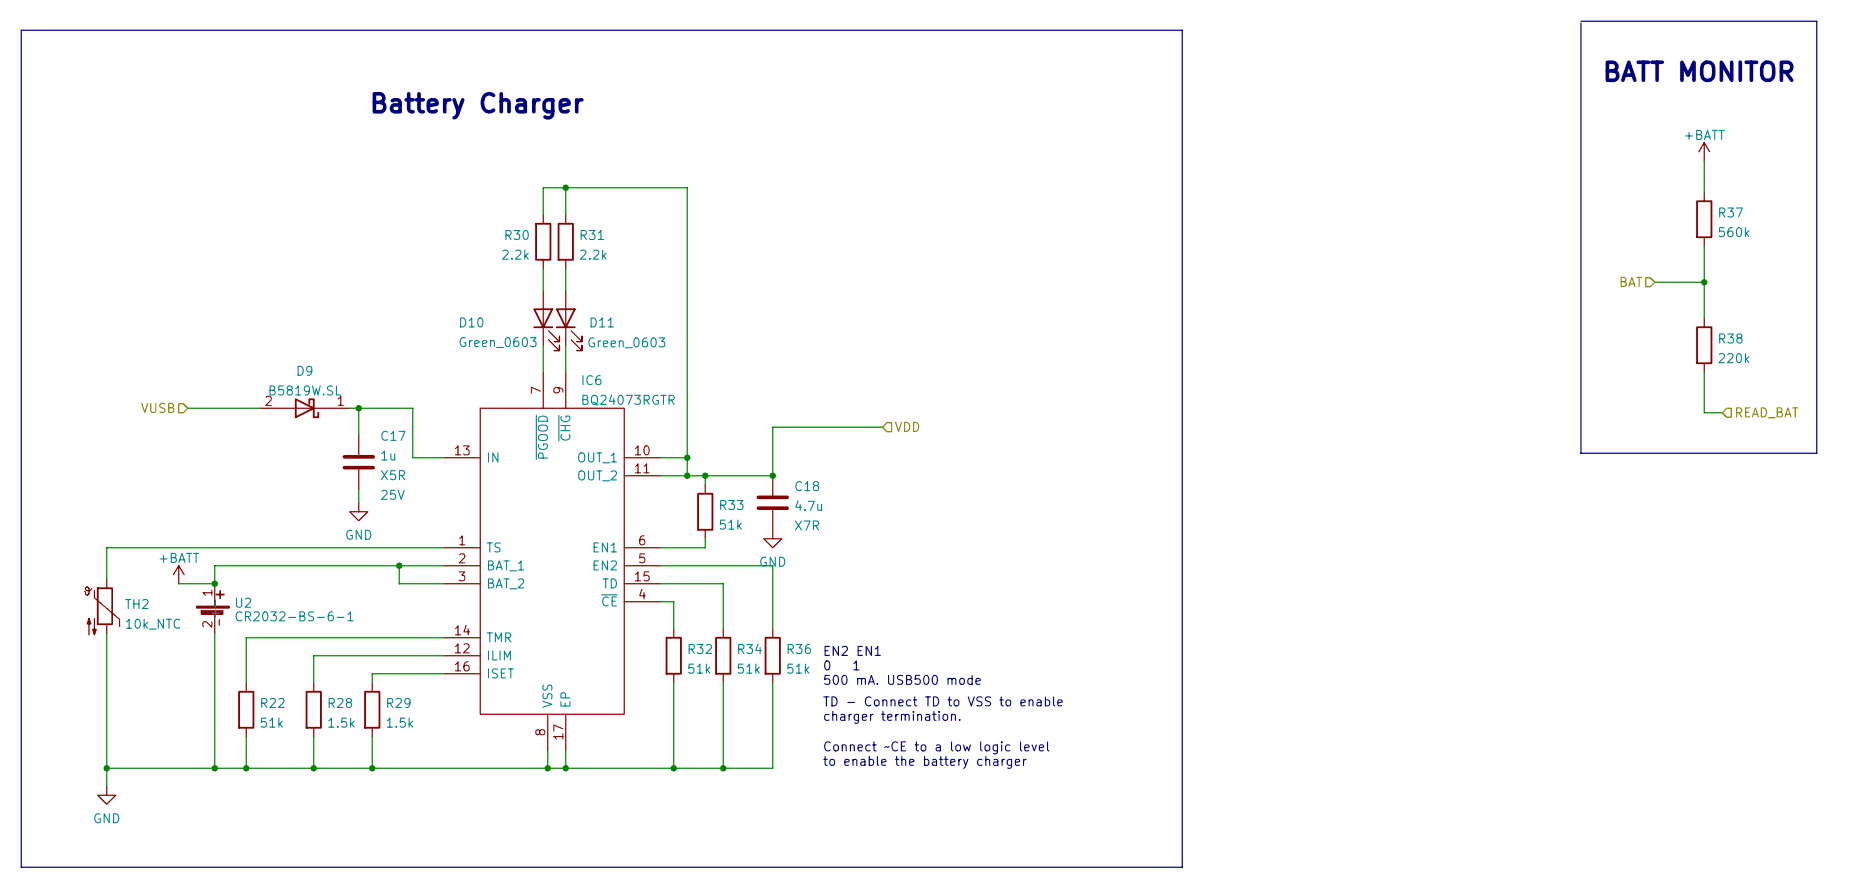
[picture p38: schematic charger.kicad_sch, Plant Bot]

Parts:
C17: 1u; C_0402_1005Metric; Voltage 25V; LCSC C52923
C18: 4.7u; C_1206_3216Metric; Rating 50V; LCSC C29823
D9: B5819W.SL; B5819WSL; Manufacturer_Part_Number B5819W.SL; LCSC C8598
D10, D11: Green_0603; LED_0603_1608Metric; LCSC C72043
IC6: BQ24073RGTR; QFN50P300X300X100-17N-D; Manufacturer_Part_Number BQ24073RGTR; Mouser Part Number 595-BQ24073RGTR
R22, R32, R33, R34, R36: 51k; R_0402_1005Metric; LCSC C25794
R28, R29: 1.5k; R_0402_1005Metric; LCSC C25867
R30, R31: 2.2k; R_0402_1005Metric; LCSC C25879
R37: 560k; R_0603_1608Metric; LCSC C23203
R38: 220k; R_0402_1005Metric; LCSC C25767
TH2: 10k_NTC; R_0402_1005Metric; MPN NCU15XH103F6SRC; LCSC C333993
U2: CR2032-BS-6-1; CR2032BS61; Manufacturer_Part_Number CR2032-BS-6-1; LCSC C70377

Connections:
+BATT: IC6.2 (BAT_1), IC6.3 (BAT_2), R37.1, U2.1 (+)
/Battery Charger/BAT: R37.2, R38.1; also elsewhere on the board
/Battery Charger/READ_BAT: R38.2; also elsewhere on the board
/Battery Charger/VUSB: D9.2; also elsewhere on the board
GND: C17.2, C18.2, IC6.8 (VSS), IC6.17 (EP), R22.2, R28.2, R29.2, R32.2, R34.2, R36.2, TH2.2, U2.2 (-); also elsewhere on the board
unnamed: D10.2 (A), R30.1
unnamed: D10.1 (K), IC6.7 (~PGOOD)
unnamed: D11.2 (A), R31.2
unnamed: D11.1 (K), IC6.9 (~CHG)
unnamed: IC6.6 (EN1), R33.2
unnamed: IC6.5 (EN2), R36.1
unnamed: IC6.12 (ILIM), R28.1
unnamed: C17.1, D9.1, IC6.13 (IN)
unnamed: IC6.16 (ISET), R29.1
unnamed: IC6.15 (TD), R34.1
unnamed: IC6.14 (TMR), R22.1
unnamed: IC6.1 (TS), TH2.1
unnamed: IC6.4 (~CE), R32.1
VDD: C18.1, IC6.10 (OUT_1), IC6.11 (OUT_2), R30.2, R31.1, R33.1; also elsewhere on the board

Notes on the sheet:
Connect ~CE to a low logic level to enable the battery charger
TD - Connect TD to VSS to enable charger termination.
Battery Charger
BATT MONITOR
EN2 EN1 0 1 500 mA. USB500 mode

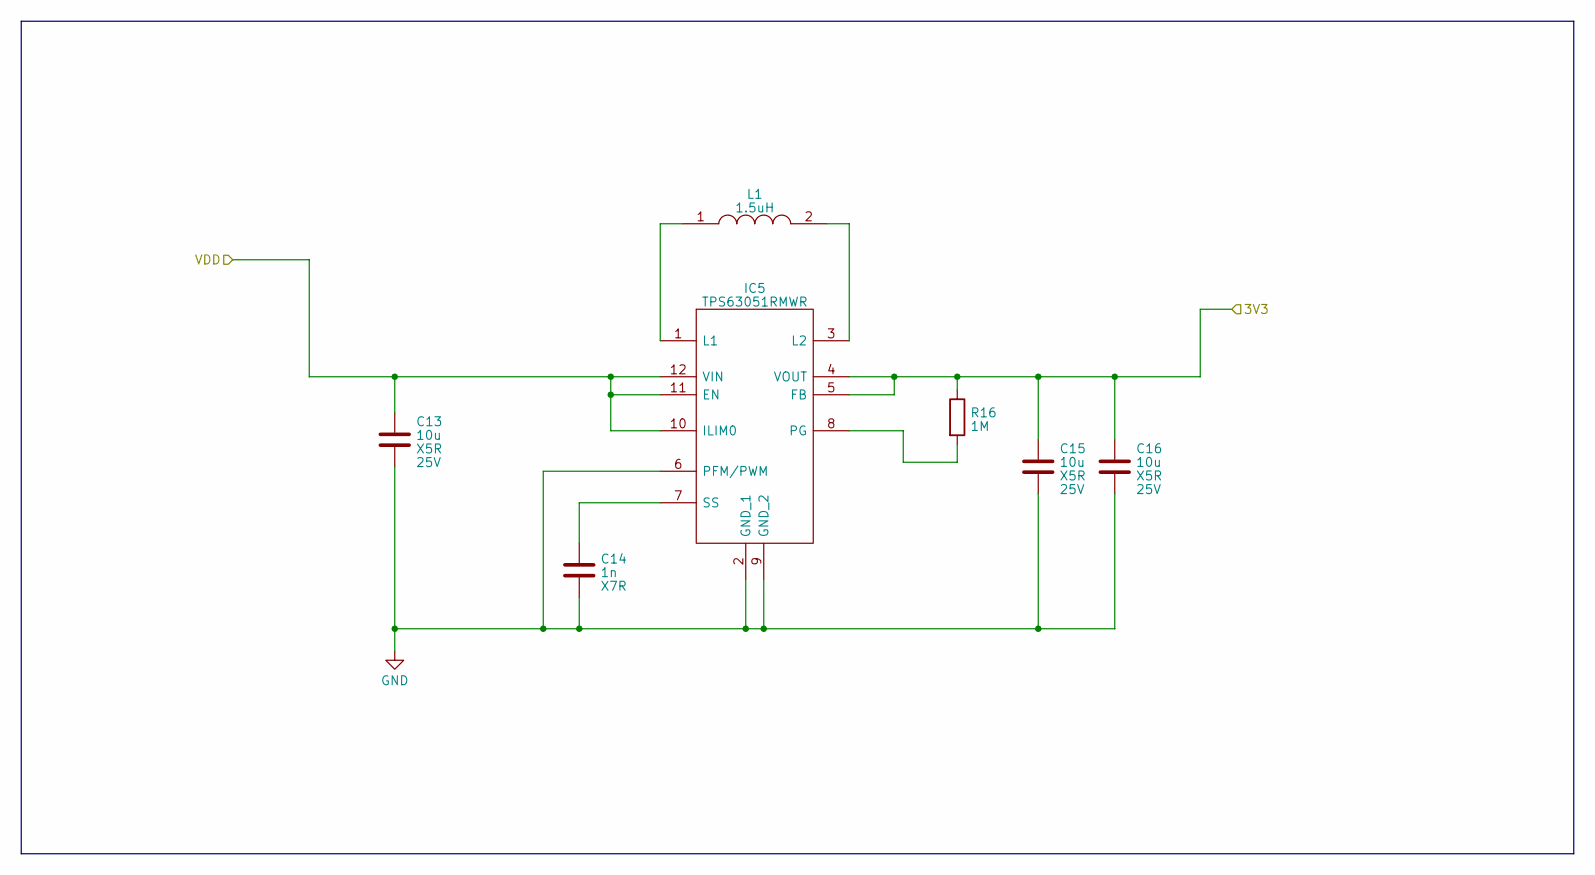
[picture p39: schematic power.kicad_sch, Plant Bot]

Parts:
C13, C15, C16: 10u; C_0805_2012Metric; Voltage 25V; LCSC C15850
C14: 1n; C_0402_1005Metric; LCSC C1523
IC5: TPS63051RMWR; QFN50P250X250X100-12N-D; Manufacturer_Part_Number TPS63051RMWR; Mouser Part Number 595-TPS63051RMWR
L1: 1.5uH; L_0805_2012Metric; LCSC C2042639
R16: 1M; R_0402_1005Metric; LCSC C26083

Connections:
+3V3: C15.1, C16.1, IC5.4 (VOUT), IC5.5 (FB), R16.1; also elsewhere on the board
GND: C13.2, C14.2, C15.2, C16.2, IC5.2 (GND_1), IC5.6 (PFM/PWM), IC5.9 (GND_2); also elsewhere on the board
unnamed: IC5.1 (L1), L1.1
unnamed: IC5.3 (L2), L1.2
unnamed: IC5.8 (PG), R16.2
unnamed: C14.1, IC5.7 (SS)
VDD: C13.1, IC5.10 (ILIM0), IC5.11 (EN), IC5.12 (VIN); also elsewhere on the board

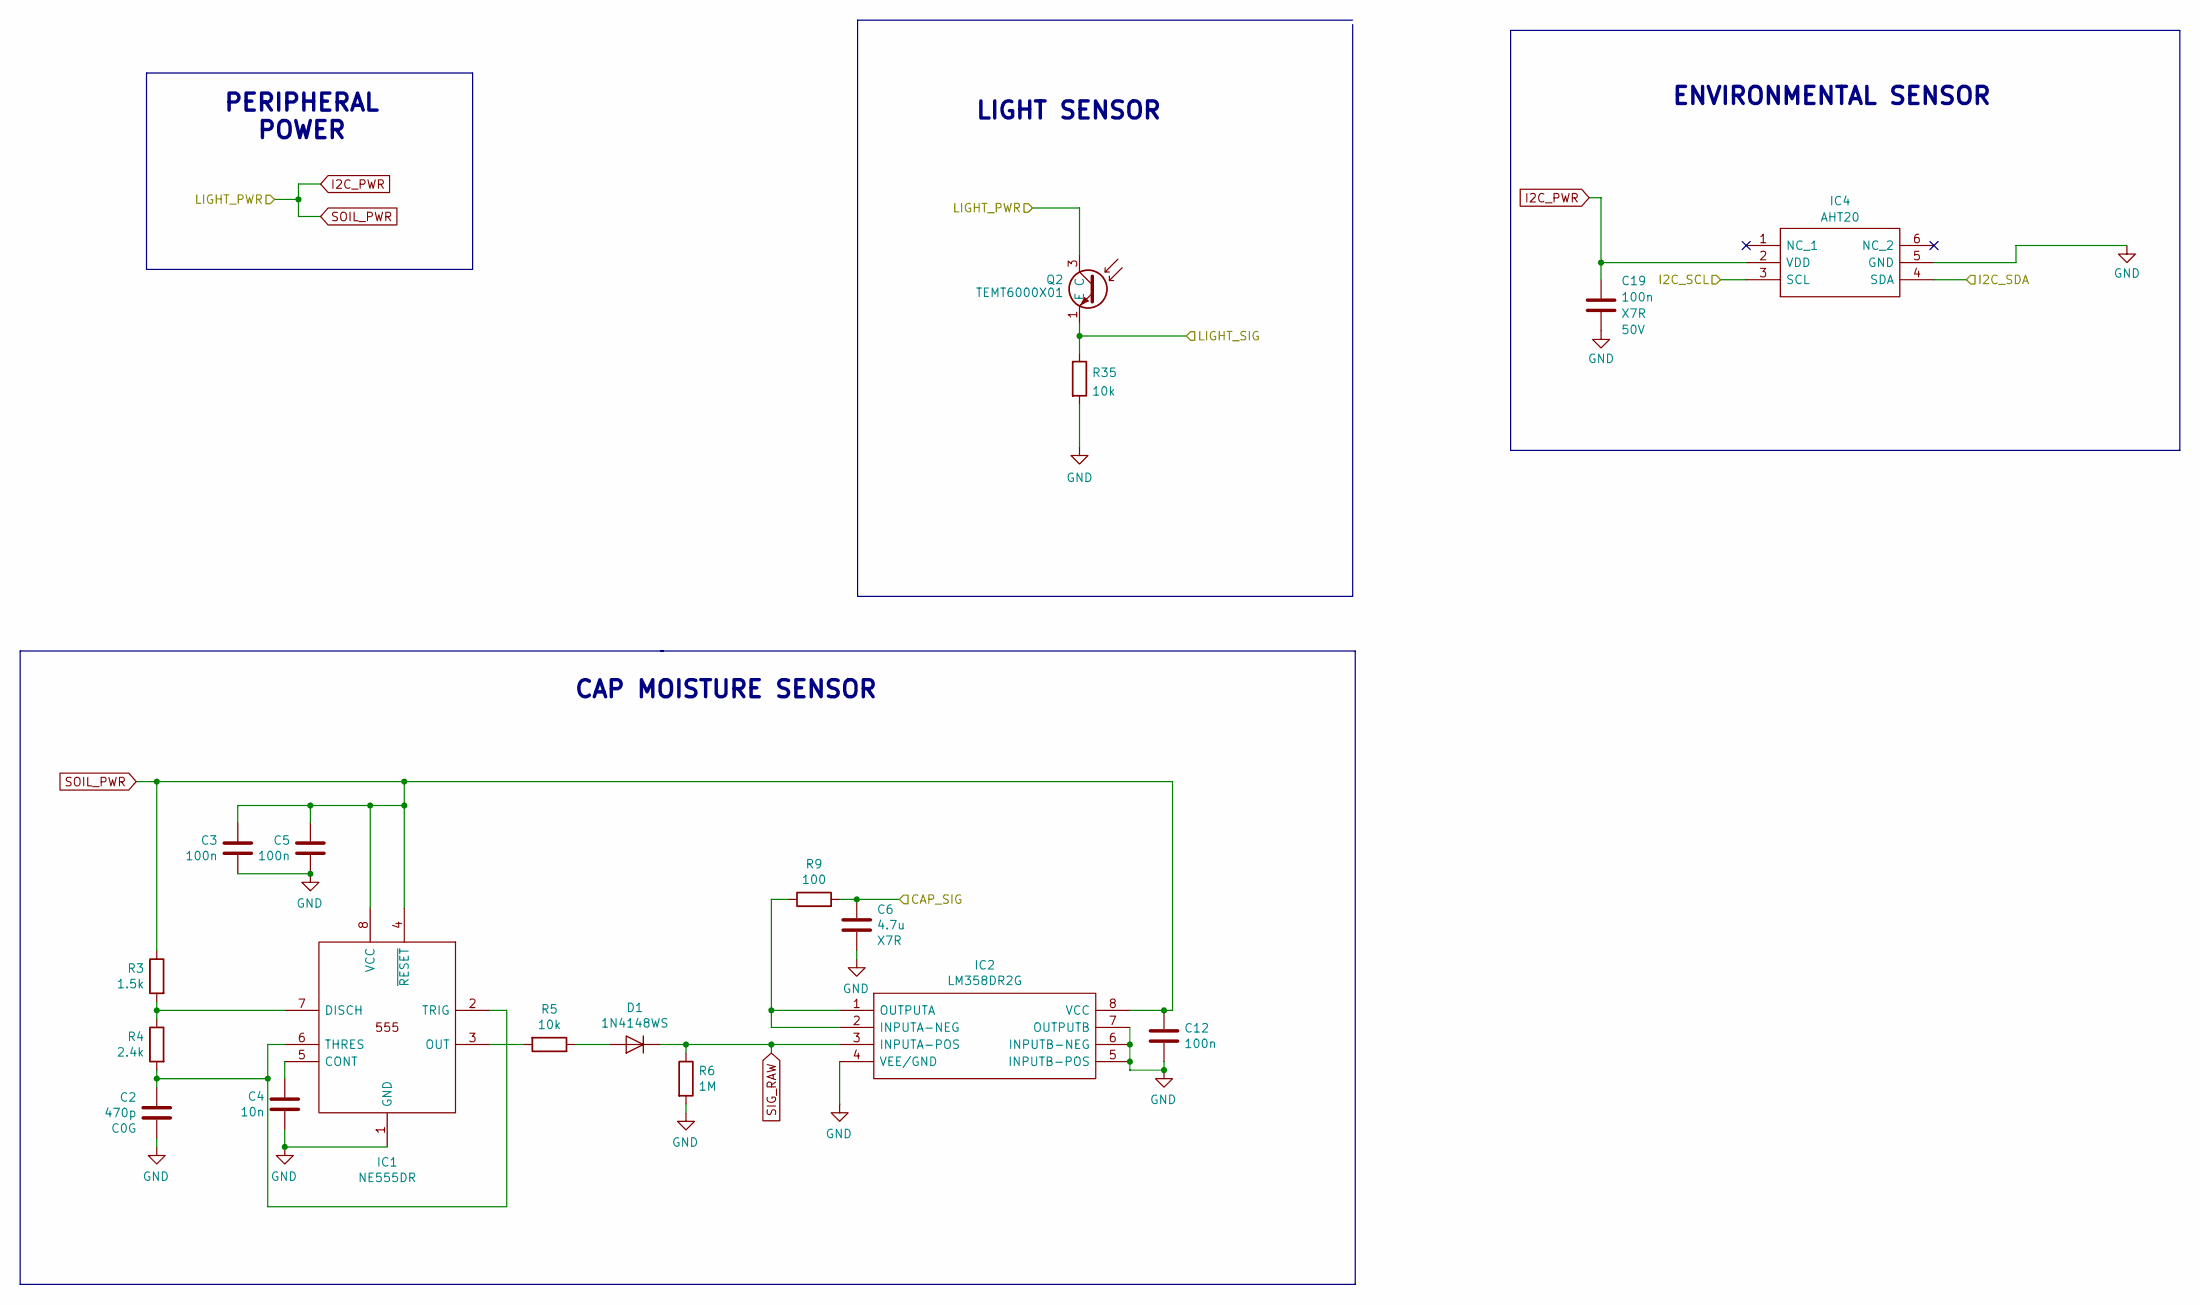
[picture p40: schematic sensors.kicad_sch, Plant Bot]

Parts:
C2: 470p; C_0603_1608Metric; Rating 25V; LCSC C1620
C3, C5, C12: 100n; C_0402_1005Metric; LCSC C307331
C4: 10n; C_0402_1005Metric; LCSC C15195
C6: 4.7u; C_1206_3216Metric; Rating 50V; LCSC C29823
C19: 100n; C_0402_1005Metric; Voltage 50V; LCSC C307331
D1: 1N4148WS; D_SOD-323F; LCSC C2128
IC1: NE555DR; SOIC127P600X175-8N; Manufacturer_Part_Number NE555DR; Mouser Part Number 595-NE555DR
IC2: LM358DR2G; SOIC127P600X175-8N; Mouser Part Number 863-LM358DR2G
IC4: AHT20; Manufacturer_Part_Number AHT20; LCSC C2757850
Q2: TEMT6000X01; Manufacturer_Part_Number TEMT6000X01; Mouser Part Number 78-TEMT6000
R3: 1.5k; R_0402_1005Metric; LCSC C25867
R4: 2.4k; R_0402_1005Metric; LCSC C25882
R5, R35: 10k; R_0402_1005Metric; LCSC C25744
R6: 1M; R_0402_1005Metric; LCSC C26083
R9: 100; R_0402_1005Metric; LCSC C25076

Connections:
/Microcontroller/CAP_SIG: C6.1, R9.2; also elsewhere on the board
/Microcontroller/I2C_SCL: IC4.3 (SCL); also elsewhere on the board
/Microcontroller/I2C_SDA: IC4.4 (SDA); also elsewhere on the board
/Microcontroller/LIGHT_SIG: Q2.1 (E), Q2.2 (E), R35.1; also elsewhere on the board
GND: C2.2, C3.2, C4.2, C5.2, C6.2, C12.2, C19.2, IC1.1 (GND), IC2.4 (VEE/GND), IC2.5 (INPUTB-POS), IC2.6 (INPUTB-NEG), IC2.7 (OUTPUTB), IC4.5 (GND), R6.2, R35.2; also elsewhere on the board
I2C_PWR: C3.1, C5.1, C12.1, C19.1, IC1.4 (~RESET), IC1.8 (VCC), IC2.8 (VCC), IC4.2 (VDD), Q2.3 (C), R3.1; also elsewhere on the board
unnamed: D1.2 (A), R5.1
unnamed: C4.1, IC1.5 (CONT)
unnamed: IC1.7 (DISCH), R3.2, R4.1
unnamed: IC1.3 (OUT), R5.2
unnamed: C2.1, IC1.2 (TRIG), IC1.6 (THRES), R4.2
unnamed: IC2.1 (OUTPUTA), IC2.2 (INPUTA-NEG), R9.1
SIG_RAW: D1.1 (K), IC2.3 (INPUTA-POS), R6.1

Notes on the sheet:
ENVIRONMENTAL SENSOR
CAP MOISTURE SENSOR
PERIPHERAL POWER
LIGHT SENSOR

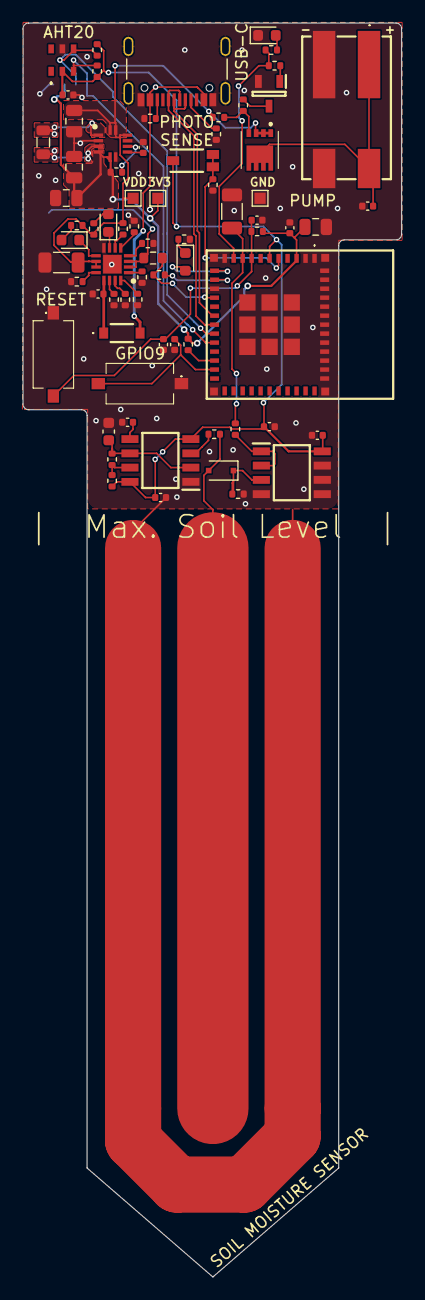
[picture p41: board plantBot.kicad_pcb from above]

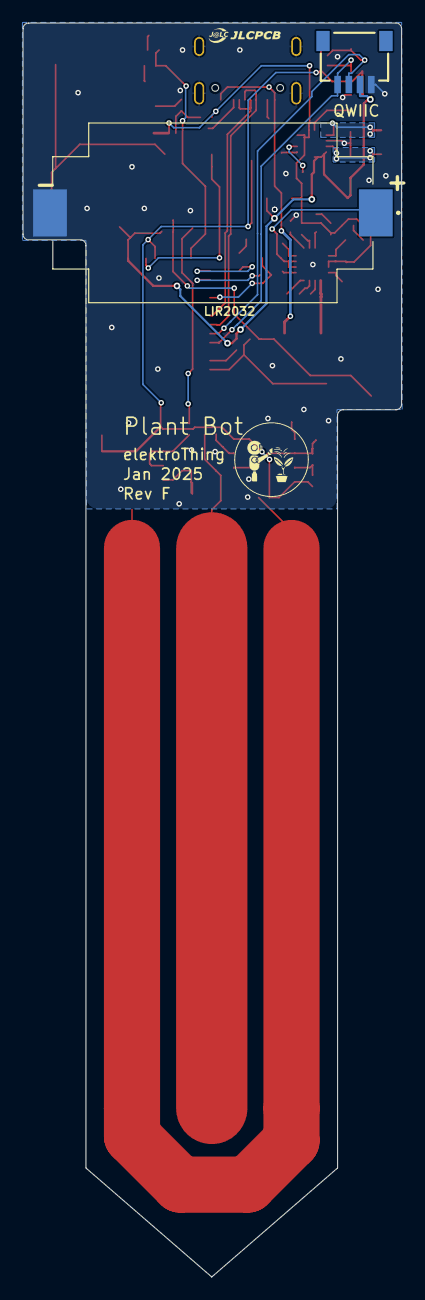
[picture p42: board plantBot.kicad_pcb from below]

Board: 2 copper layers, 33.7 x 111.6 mm, 77 parts (5 on the bottom side), 51 nets.

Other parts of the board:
F*: LOGO; logo_10mm

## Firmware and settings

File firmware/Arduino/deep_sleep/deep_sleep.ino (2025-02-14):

/*
Simple Deep Sleep with Timer Wake Up
=====================================
ESP32 offers a deep sleep mode for effective power
saving as power is an important factor for IoT
applications. In this mode CPUs, most of the RAM,
and all the digital peripherals which are clocked
from APB_CLK are powered off. The only parts of
the chip which can still be powered on are:
RTC controller, RTC peripherals ,and RTC memories

This code displays the most basic deep sleep with
a timer to wake it up and how to store data in
RTC memory to use it over reboots

This code is under Public Domain License.

Author:
Pranav Cherukupalli <cherukupallip@gmail.com>
*/

#define uS_TO_S_FACTOR 1000000ULL /* Conversion factor for micro seconds to seconds */
#define TIME_TO_SLEEP  11          /* Time ESP32 will go to sleep (in seconds) */

RTC_DATA_ATTR int bootCount = 0;

/*
Method to print the reason by which ESP32
has been awaken from sleep
*/
void print_wakeup_reason() {
  esp_sleep_wakeup_cause_t wakeup_reason;

  wakeup_reason = esp_sleep_get_wakeup_cause();

  switch (wakeup_reason) {
    case ESP_SLEEP_WAKEUP_EXT0:     Serial.println("Wakeup caused by external signal using RTC_IO"); break;
    case ESP_SLEEP_WAKEUP_EXT1:     Serial.println("Wakeup caused by external signal using RTC_CNTL"); break;
    case ESP_SLEEP_WAKEUP_TIMER:    Serial.println("Wakeup caused by timer"); break;
    case ESP_SLEEP_WAKEUP_TOUCHPAD: Serial.println("Wakeup caused by touchpad"); break;
    case ESP_SLEEP_WAKEUP_ULP:      Serial.println("Wakeup caused by ULP program"); break;
    default:                        Serial.printf("Wakeup was not caused by deep sleep: %d\n", wakeup_reason); break;
  }
}

void setup() {
  Serial.begin(115200);
  delay(1000);  //Take some time to open up the Serial Monitor
  pinMode(0, OUTPUT);
  // pinMode(1, OUTPUT);
  // pinMode(2, OUTPUT);
  pinMode(3, OUTPUT);
  pinMode(21, OUTPUT);
  pinMode(22, OUTPUT);
  pinMode(23, OUTPUT);


  digitalWrite(0, LOW);
  // digitalWrite(1, LOW);
  // digitalWrite(2, LOW);
  digitalWrite(3, LOW);
  digitalWrite(21, LOW);
  digitalWrite(22, LOW);
  digitalWrite(23, LOW);

  //Increment boot number and print it every reboot
  ++bootCount;
  Serial.println("Boot number: " + String(bootCount));
  
  gpio_hold_en(GPIO_NUM_0);
  // gpio_hold_en(GPIO_NUM_1);
  // gpio_hold_en(GPIO_NUM_2);
  gpio_hold_en(GPIO_NUM_3);
  gpio_hold_en(GPIO_NUM_21);
  gpio_hold_en(GPIO_NUM_22);
  gpio_hold_en(GPIO_NUM_23);

  //Print the wakeup reason for ESP32
  print_wakeup_reason();

  /*
  First we configure the wake up source
  We set our ESP32 to wake up every 5 seconds
  */
  esp_sleep_enable_timer_wakeup(TIME_TO_SLEEP * uS_TO_S_FACTOR);
  Serial.println("Setup ESP32 to sleep for every " + String(TIME_TO_SLEEP) + " Seconds");

  /*
  Next we decide what all peripherals to shut down/keep on
  By default, ESP32 will automatically power down the peripherals
  not needed by the wakeup source, but if you want to be a poweruser
  this is for you. Read in detail at the API docs
  http://esp-idf.readthedocs.io/en/latest/api-reference/system/deep_sleep.html
  Left the line commented as an example of how to configure peripherals.
  The line below turns off all RTC peripherals in deep sleep.
  */
  //esp_deep_sleep_pd_config(ESP_PD_DOMAIN_RTC_PERIPH, ESP_PD_OPTION_OFF);
  //Serial.println("Configured all RTC Peripherals to be powered down in sleep");

  /*
  Now that we have setup a wake cause and if needed setup the
  peripherals state in deep sleep, we can now start going to
  deep sleep.
  In the case that no wake up sources were provided but deep
  sleep was started, it will sleep forever unless hardware
  reset occurs.
  */
  Serial.println("Going to sleep now");
  Serial.flush();
  esp_deep_sleep_start();
  Serial.println("This will never be printed");
}

void loop() {
  //This is not going to be called
}

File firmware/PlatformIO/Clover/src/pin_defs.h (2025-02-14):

#ifndef PINS_DEFS_H
#define PINS_DEFS_H

#define DEBUG_LED 0
#define BAT 0
#define READ_BATT 1
#define LED_DAT 2
// #define LED_DAT 8
#define LED_PWR 3
#define SDA 14
#define SCL 15
#define RED_PIN 21
#define GREEN_PIN 22
#define YELLOW_PIN 23

#endif // PINS_DEFS_H

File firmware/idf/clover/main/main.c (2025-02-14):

/*
 * SPDX-FileCopyrightText: 2024 Espressif Systems (Shanghai) CO LTD
 *
 * SPDX-License-Identifier: Unlicense OR CC0-1.0
 */

/* Standard includes */
#include <stdio.h>
#include <string.h>

/* ESP-IDF includes */
#include "nvs_flash.h"
#include "esp_log.h"
#include "esp_sleep.h"
#include "freertos/FreeRTOS.h"
#include "freertos/task.h"

/* Application includes */
#include "common.h"
#include "gap.h"
#include "gatt_svc.h"
#include "heart_rate.h"
#include "led.h"
#include "deep_sleep.h"

/* Duty cycle configuration */
#define DUTY_CYCLE_PERCENTAGE    0.1f     // Set your desired duty cycle here (0.1% to 100%)
#define MIN_ACTIVE_TIME_MS       500      // Minimum active time due to startup requirements

/* Task configuration */
#define NIMBLE_TASK_STACK_SIZE    (4 * 1024)
#define HEART_RATE_TASK_STACK_SIZE (4 * 1024)
#define TASK_PRIORITY_NORMAL      5

/* Global variables */
static uint32_t g_active_time_ms;
static uint32_t g_sleep_time_ms;

/* Function declarations */
static void on_stack_reset(int reason);
static void on_stack_sync(void);
static void nimble_host_config_init(void);
static void nimble_host_task(void *param);
static void heart_rate_task(void *param);

/* Calculate sleep time based on duty cycle */
static void calculate_timing(void) {
    g_active_time_ms = MIN_ACTIVE_TIME_MS;
    g_sleep_time_ms = (uint32_t)((MIN_ACTIVE_TIME_MS / DUTY_CYCLE_PERCENTAGE * 100.0f) - MIN_ACTIVE_TIME_MS);
    
    ESP_LOGI(TAG, "Duty Cycle Configuration:");
    ESP_LOGI(TAG, "  Target: %.3f%%", DUTY_CYCLE_PERCENTAGE);
    ESP_LOGI(TAG, "  Active Time: %d ms", g_active_time_ms);
    ESP_LOGI(TAG, "  Sleep Time: %d ms", g_sleep_time_ms);
}

/* BLE stack callbacks */
static void on_stack_reset(int reason) {
    ESP_LOGI(TAG, "NimBLE stack reset, reason: %d", reason);
}

static void on_stack_sync(void) {
    ESP_LOGI(TAG, "NimBLE stack synchronized");
    adv_init();
}

/* NimBLE host configuration */
static void nimble_host_config_init(void) {
    ble_hs_cfg.reset_cb = on_stack_reset;
    ble_hs_cfg.sync_cb = on_stack_sync;
    ble_hs_cfg.gatts_register_cb = gatt_svr_register_cb;
    ble_hs_cfg.store_status_cb = ble_store_util_status_rr;
}

/* Task implementations */
static void nimble_host_task(void *param) {
    ESP_LOGI(TAG, "NimBLE host task started");
    nimble_port_run();
    nimble_port_deinit();
    vTaskDelete(NULL);
}

static void heart_rate_task(void *param) {
    ESP_LOGI(TAG, "Heart rate task started");
    
    while (1) {
        update_heart_rate();
        ESP_LOGI(TAG, "Heart rate updated to %d", get_heart_rate());
        send_heart_rate_indication();
        vTaskDelay(HEART_RATE_TASK_PERIOD);
    }
}

/* Main application entry point */
void app_main(void) {
    esp_err_t ret;
    
    /* Calculate timing based on duty cycle */
    calculate_timing();
    
    /* Initialize LED */
    led_init();
    
    /* Initialize NVS flash */
    ret = nvs_flash_init();
    if (ret == ESP_ERR_NVS_NO_FREE_PAGES || ret == ESP_ERR_NVS_NEW_VERSION_FOUND) {
        ESP_ERROR_CHECK(nvs_flash_erase());
        ret = nvs_flash_init();
    }
    
    /* Initialize BLE stack */
    ret = nimble_port_init();
    if (ret != ESP_OK) {
        return;
    }
    
    gap_init();
    gatt_svc_init();
    nimble_host_config_init();
    
    /* Create tasks */
    xTaskCreate(nimble_host_task, "NimBLE Host", NIMBLE_TASK_STACK_SIZE,
                NULL, TASK_PRIORITY_NORMAL, NULL);
    xTaskCreate(heart_rate_task, "Heart Rate", HEART_RATE_TASK_STACK_SIZE,
                NULL, TASK_PRIORITY_NORMAL, NULL);
    
    /* Stay active for the minimum required time */
    vTaskDelay(pdMS_TO_TICKS(g_active_time_ms));
    
    /* Configure sleep time and enter deep sleep */
    ESP_LOGI(TAG, "Entering deep sleep for %d ms", g_sleep_time_ms);
    deep_sleep_duration(g_sleep_time_ms * 1000ULL);
    
    // deep_sleep_forever();
}

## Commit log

2023-06-19 created step file
    [PlantBot.kicad_sch, bom.csv, capacitive.kicad_sch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]
2023-08-13 Added demo scripts
    [plantBot.kicad_pcb, power.kicad_sch, sensors.kicad_sch]
2023-08-13 Updated with latest production files and code
    [PlantBot.kicad_sch, USB.kicad_sch, bom.csv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]
2025-01-11 Restored pcb design
    [PlantBot.kicad_sch, USB.kicad_sch, button.kicad_sch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]
2025-01-11 Completed initial schematic
    [PlantBot.kicad_sch, USB.kicad_sch, capacitive.kicad_sch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]
2025-01-18 updated design
    [PlantBot.kicad_sch, charger.kicad_sch, microcontroller.kicad_sch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]
2025-01-18 created fab files
    [PlantBot.kicad_sch, bom.csv, designators.csv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]
2025-01-22 updated prod files with fiducials
    [PlantBot.kicad_sch, charger.kicad_sch, designators.csv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]
2025-02-14 Created firmware files
    [anti_rollback_partition.csv, esp_efuse_custom_table.csv, nvs_data.csv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]
